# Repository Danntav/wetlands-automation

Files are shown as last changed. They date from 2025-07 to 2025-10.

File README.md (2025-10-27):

# Wetlands Automation System

An IoT-based automation system for monitoring and controlling wetland reactors in environmental research applications.

## Overview

This system implements a complete automation solution for wetland reactor monitoring using a distributed sensor network. The architecture consists of a master ESP32 unit with embedded HMI (LCD display and joystick) that coordinates data collection from up to 9 slave units via ESP-NOW wireless protocol. The master unit manages local control, real-time visualization, alarm monitoring, and fault-tolerant data logging to SD card.

## System Architecture

The system uses a master-slave architecture where the master ESP32 coordinates periodic data collection from distributed slave units. Communication is handled via ESP-NOW protocol for low-power wireless operation. The master unit features an interactive HMI for field operation, stores timestamped data with fault redundancy using an RTC module, and implements comprehensive alarm management for sensor anomalies and communication timeouts.

## Hardware Components

**Master Unit:**
- ESP32 microcontroller
- ST7735 LCD display (SPI interface)
- Analog joystick for menu navigation
- DS1307 RTC module (I2C)
- SD card module for data logging
- 3x RGB LED indicators for system status
- Custom PCB designed in KiCAD
- 3D-printed enclosure (SolidWorks)

**Slave Units:**
- ESP32 microcontroller
- Voltage and temperature sensors
- Wireless communication via ESP-NOW

## Software Implementation

The firmware is written in C/C++ using the Arduino framework. Key features include:

- **ESP-NOW Communication:** Implements request-response protocol with ACK for reliable data transfer between master and slaves
- **Real-time Clock:** DS1307 RTC provides accurate timestamps for all data points
- **Data Collection Cycle:** Configurable 30-minute intervals for automated sensor polling
- **Buffered Writing:** Collects data from all slaves before writing to SD card to minimize file operations
- **Alarm System:** Monitors voltage thresholds, temperature ranges, sensor failures, and communication timeouts
- **Interactive HMI:** Multi-screen menu system for viewing live data, historical logs, system status, and alarms
- **Fault Tolerance:** Redundant write verification and error recovery mechanisms

### Libraries Used

- **ESP-NOW & WiFi** version & version 1.2.7, Wireless communication stack
- **RTClib** version 2.1.4, DS1307 real-time clock interface
- **SD** version 1.3.0, SD card file system management
- **Adafruit_GFX & Adafruit_ST7735** version 1.12.1 & version 1.11.0, Display graphics and ST7735 driver
- **Wire** I2C communication for RTC

## Key Features

- Automatic data collection at configurable intervals (default: 30 minutes)
- Support for up to 9 distributed slave nodes
- Real-time monitoring with timestamped data
- Comprehensive alarm system with visual and logged notifications
- Field-accessible HMI with joystick navigation
- CSV data format for easy post-processing
- System health monitoring with LED status indicators
- Communication timeout detection and alerts

## Getting Started

### Hardware Setup

1. Assemble the master PCB with ESP32, display, RTC, SD module, and joystick
2. Install components in the 3D-printed enclosure
3. Program each slave unit with unique MAC address
4. Deploy slave units at monitoring locations
5. Power on the system and verify all slaves are detected

### Software Installation

```bash
git clone https://github.com/Danntav/wetlands-automation.git
cd wetlands-automation
```

Install required libraries in Arduino IDE, configure ESP32 board settings, and update slave MAC addresses in the master firmware before uploading.

## Project Structure

```
wetlands-automation/
├── firmware/
│   ├── master/
│   │   ├── master.ino
│   │   ├── MenuManager.h
│   │   ├── LedAnimations.h
│   │   └── DataStructures.h
│   └── slave/
├── hardware/
│   ├── pcb/              # KiCAD PCB files
│   └── enclosure/        # SolidWorks 3D models
└── docs/
```

## HMI Operation

The embedded Human-Machine Interface provides:
- **Main Menu:** System overview with active slave count and last update times
- **Board Data:** Individual slave readings with voltage and temperature
- **Alarms:** Real-time alerts for sensor anomalies and communication failures
- **Error Log:** Historical system errors with timestamps
- **System Info:** RTC status, SD card status, and overall health

Navigation is performed using the analog joystick (up/down/left/right/click).

## Data Logging

Data is logged in CSV format with the following structure:
```
Date,Time,BoardID,Voltage,Temperature
```

The system implements:
- Buffered writes to minimize SD card wear
- Automatic file creation with headers
- Timestamp verification via RTC
- Error logging for failed operations
- Visual feedback via LED indicators

## Alarm System

The system monitors and alerts for:
- Voltage readings outside safe range (configurable thresholds)
- Temperature anomalies beyond expected limits
- Sensor hardware failures (invalid readings)
- Communication timeouts (no response from slaves)

Alarms are displayed on the HMI, stored in memory, and indicated via blinking red LED.

## Configuration

System parameters can be adjusted in the firmware:
- `COLLECTION_INTERVAL_MS`: Data collection frequency (default: 30 minutes)
- `VOLTAGE_MIN/MAX`: Voltage alarm thresholds
- `TEMP_MIN/MAX`: Temperature alarm thresholds
- `COMM_TIMEOUT_MS`: Communication timeout duration
- `TOTAL_SLAVES`: Number of connected slave units

## Contributing

Contributions, issues, and feature requests are welcome. Feel free to check the issues page or submit pull requests.

## License

MIT License - see [LICENSE](LICENSE) file for details.

## Author

**Daniel Oliveira Tavares**

LinkedIn: [daniel-otavares](https://www.linkedin.com/in/daniel-otavares)

Email: danieloftavares@gmail.com

GitHub: [@Danntav](https://github.com/Danntav)

## Future Improvements

- [ ] Cloud connectivity for remote monitoring via MQTT or HTTP
- [ ] Mobile app integration for real-time alerts
- [ ] Additional sensor types (pH, dissolved oxygen, flow rate)
- [ ] Solar power system with battery management
- [ ] Web dashboard for data visualization and historical analysis
- [ ] Machine learning for predictive maintenance
- [ ] LoRa support for extended range communication

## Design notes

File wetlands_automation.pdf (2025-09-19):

### AUTOMAÇÃO WETLANDS por SISTEMA IoT

### Yara Carvalho Gomes

A automação visa em primeiro plano agilizar o processo de coleta de informações do sistema Wetlands. Foi proposto uma solução IoT com o uso de microcontroladores e sensores para monitorar continuamente os reatores. Estes dados serão armazenados localmente em um cartão de memória, do qual pode ser removido pelo operador e inserido em um computador para futuras análises das informações coletadas.
(Caso queira ver direto a parte prática → pular para página X)

Lógica do sistema
A organização geral do sistema consiste na lógica Mestre-Escravo. Os microcontroladores Escravos são responsáveis por coletar informações de tensão e temperatura de cada reator de Wetlands, e posteriormente enviar estes dados coletados ao microcontrolador Mestre, atuante como receptor central do conjunto. Os ESP32 Escravos são identificados com um código de 1 a 9. O Mestre é único, e é responsável por tratar o tráfego de informações recebidas de todos os Escravos, e armazená-las de forma sequencial em um cartão de memória local.
Uma vez que o local de implantação do circuito conta com acesso à rede elétrica, optou-se por não utilizar baterias para alimentar o sistema IoT, evitando assim gastos. Foram utilizadas 3 fontes chaveadas 12V (Volts) e 5A (Amperes) que convertem a tensão alternada da tomada de 110v para a tensão contínua de 12v. Foi adicionado um módulo Step-Down LM2596S na saída da fonte para regular a tensão e garantir alimentação para todo o sistema.
Foi determinada a coleta de dados a cada 5 minutos, resultando em 12 medições por hora, 288 medições por dia de cada reator. Dessa maneira, garante-se alta resolução e precisão das informações adquiridas dos reatores.

Escravos
O diagrama de conexão para todos os Escravos são semelhantes. Para cada reator haverá um sistema único, com o intuito de deixá-lo modular e facilitar a depuração.
O componente principal é o microcontrolador de baixo consumo ESP32-DevKitV1 desenvolvido pela empresa Espressif Systems. Dentre algumas de suas especificações, possui: processador Xtensa Dual-Core 32-bit LX6 com clock máximo de 240MHz; memória Flash programável de 4MB e memória RAM de 520 KBytes; possui 25 portas programáveis para entrada e/ou saída de dados (GPIO). conexão Bluetooth no padrão 4.2; conexão WiFi de 2.4GHz, podendo atuar como ponto de acesso, estação ou ponto de acesso+estação [1].
Para medição da temperatura, foi escolhido o sensor DS18B20 fabricado pela empresa Dallas Semiconductor, modelo resistente à água. Opera na faixa de -10°C até +85°C com precisão de ±0.5°C. A informação coletada pelo sensor é enviada ao microcontrolador por apenas um fio [2].
A medição de tensão do sistema é realizada através do módulo conversor analógico-digital, o ADS1115, fabricado pela empresa Texas Instruments. Este possui resolução de 16-bit, moderadamente maior se comparado com o conversor analógico-digital presente no próprio ESP32, que é de 12-bit. [3]
O sistema conta também com 3 LEDs (Light Emitting Diode ou Diodo Emissor de Luz) genéricos de 5mm, para dar um feedback visual do estado do sistema. Segue abaixo o diagrama feito no software Fritzing do sistema Escravo presente em cada um dos 9 reatores.

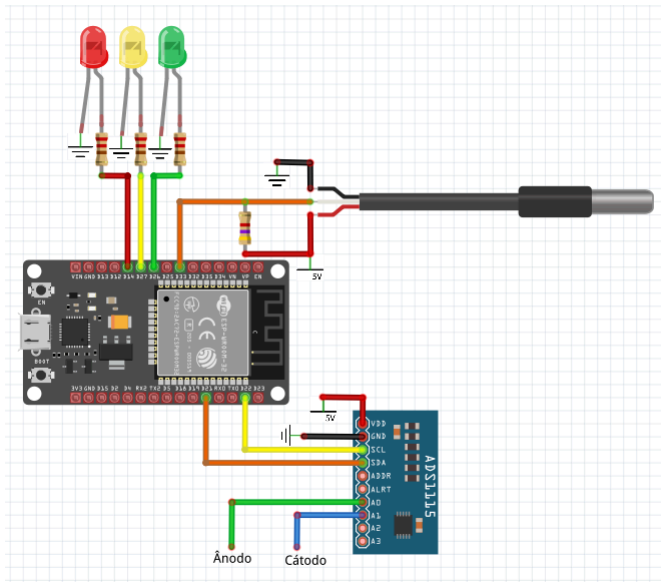
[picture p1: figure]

Mestre
O conjunto Mestre conta com módulos específicos e diferentes daqueles encontrados nos Escravos, com exceção do microcontrolador ESP32 e dos LEDs. O módulo DS1307 é um circuito integrado de relógio de tempo real (RTC, Real Time Clock) fabricado pela empresa Maxim Integrated, que conta com uma bateria e com um calendário interno. Ele marca segundos, minutos, horas, dia do mês, mês, dia da semana, ano, e faz a compensação automática para meses com menos de 31 dias e para anos bissextos. Na falta de energia, a contagem do tempo é garantida por meio de bateria. A comunicação com este módulo é feita via barramento I2C com o microcontrolador.[5]
Para salvar os dados advindos dos Escravos, foi utilizado um módulo de cartão de memória microSD genérico. Sua comunicação com o ESP principal é feita através do protocolo SPI (Serial Peripheral Interface)[6]. Os dados são gravados no cartão microSD utilizando o sistema de arquivos FAT32. Isso permite que o arquivo contento todas as informações seja lido diretamente em qualquer computador compatível.
Para facilitar a visualização de algumas informações em campo do sistema, como últimas medições dos reatores e alertas de erro, foi implementado um menu interativo composto por dois módulos. O primeiro, uma tela onde é possível visualizar as informações, o módulo genérico display LCD ST7735 TFT de 1.8 polegadas e que conta com resolução de 128x160 pixels. Sua comunicação com o Mestre é feita via SPI. O próximo, o controle para interagir com o menu, o módulo também genérico KY-023 joystick. Ele possui dois potenciômetros internos responsáveis por identificar a posição de movimento do analógico, além de um botão digital que é ativado quando o joystick é pressionado. Sua conexão com o microprocessador é feita via portas GPIO.
O sistema Mestre será colocado à parte em uma caixa específica e montado sobre uma placa de circuito impressa. O intuito é o operador interagir apenas com o módulo central Mestre, e não com os Escravos.
Segue abaixo o diagrama de conexões do ESP32 Mestre feito no software Fritzing.

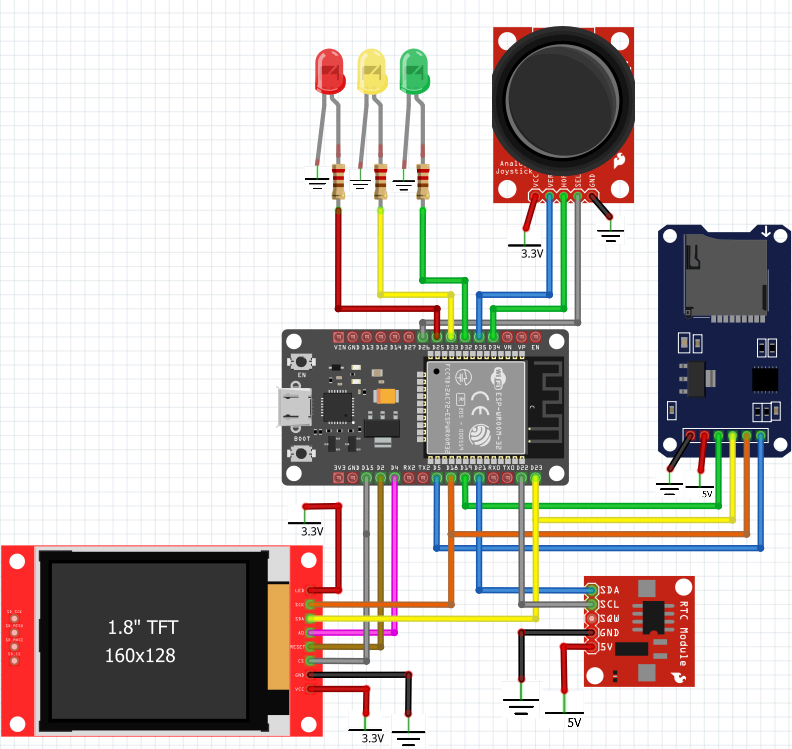
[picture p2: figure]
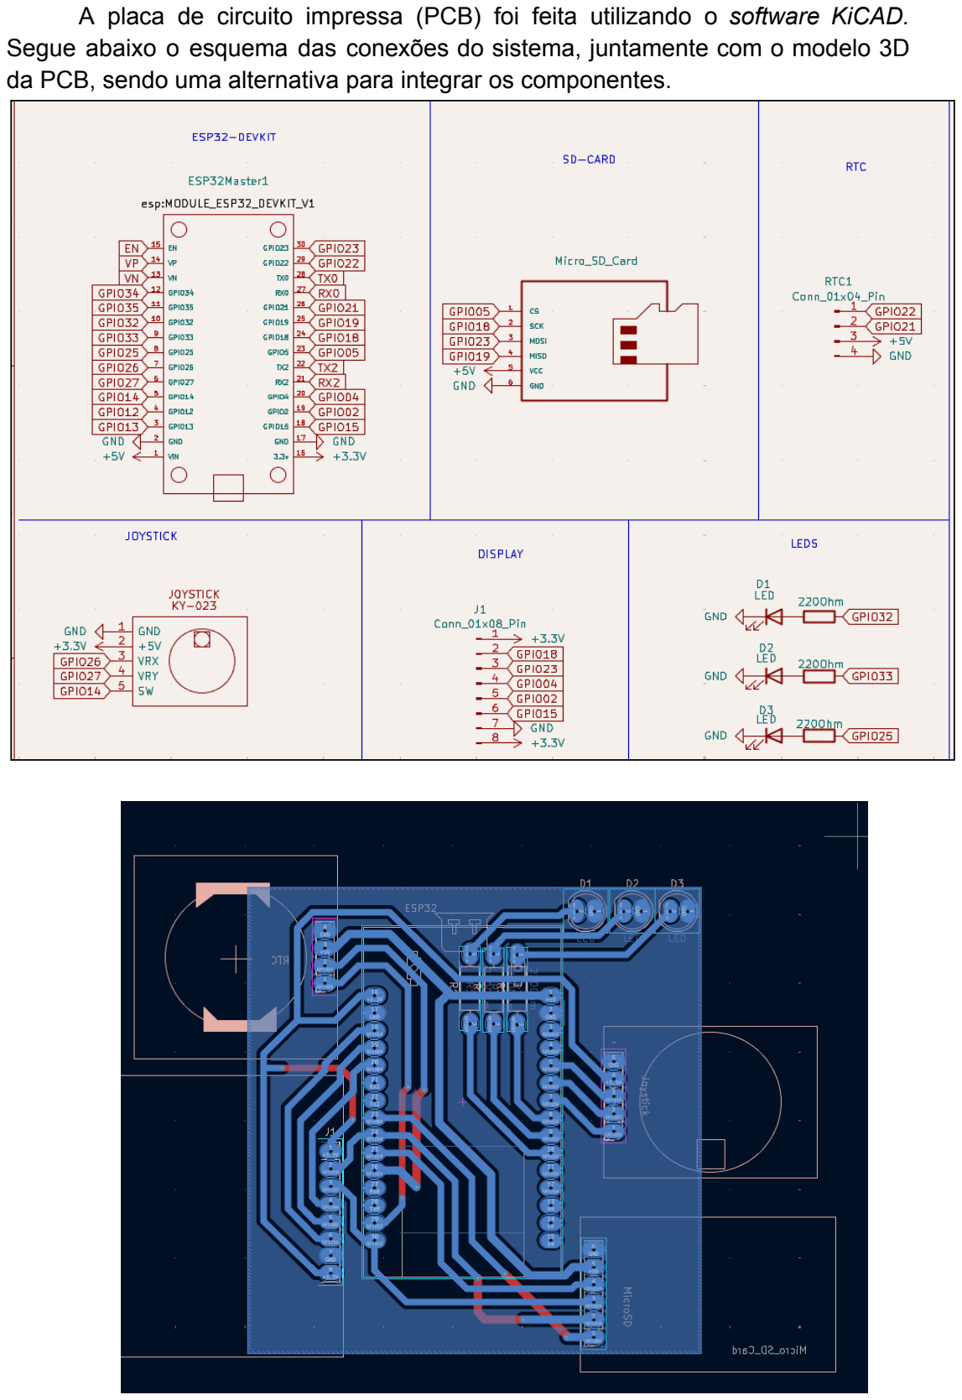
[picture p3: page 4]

A placa de circuito impressa (PCB) foi feita utilizando o software KiCAD. Segue abaixo o esquema das conexões do sistema, juntamente com o modelo 3D da PCB, sendo uma alternativa para integrar os componentes.

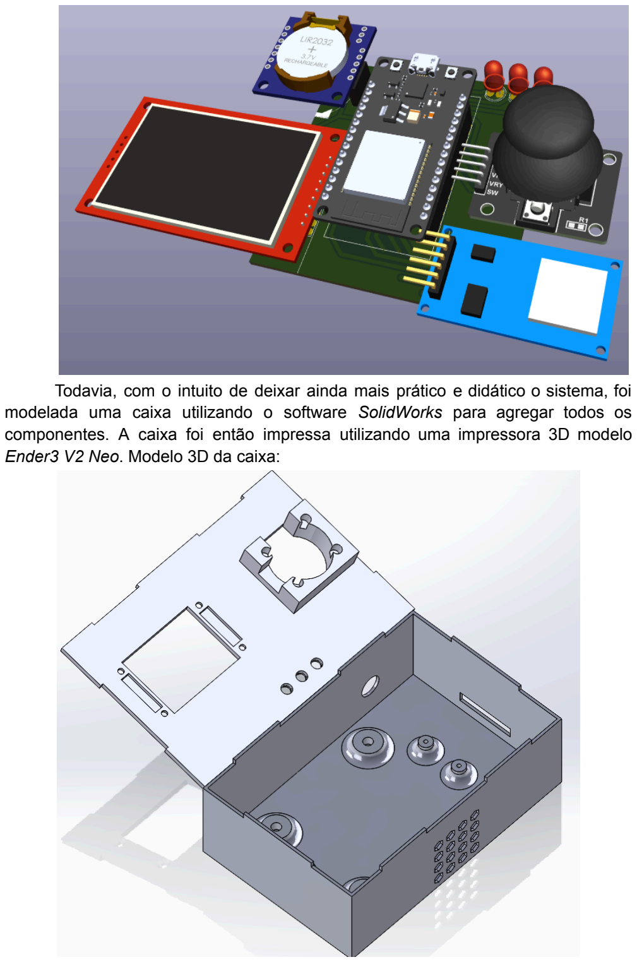
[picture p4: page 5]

Todavia, com o intuito de deixar ainda mais prático e didático o sistema, foi modelada uma caixa utilizando o software SolidWorks para agregar todos os componentes. A caixa foi então impressa utilizando uma impressora 3D modelo Ender3 V2 Neo. Modelo 3D da caixa:

Imagem do sistema real:

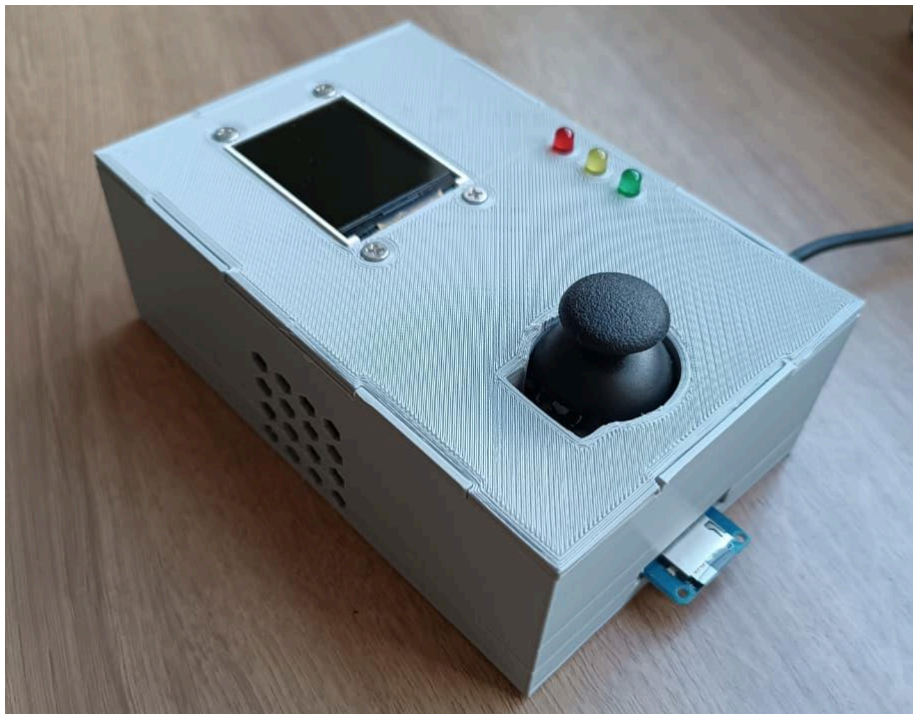
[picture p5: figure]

Passo a passo de como tudo funciona
Inicialmente, todo o sistema estará ligado e ativo. O ESP32 Mestre estará continuamente analisando o tempo do sistema baseado no módulo RTC. A cada 5 minutos (tempo estipulado anteriormente) o Mestre enviará um sinal de solicitação para o ESP32 Escravo número 1, para que este faça as medições no tanque em que está acoplado. Após o Escravo 1 coletar os dados por meio dos sensores, ele envia esta informação coletada juntamente com seu identificador (ID) para o Mestre. O Mestre armazena estes dados recebidos (adicionando também o horário de recebimento) de forma sequencial no cartão de memória.
Se o processo acontecer com sucesso no Escravo com ID 1, o Mestre envia uma mensagem de confirmação Acknowledgment (ACK) de volta ao ESP32 Escravo a fim de garantir conformidade entre os pares. Em seguida, todo o processo se repete para demais Escravos, continuamente durante todo o dia.
O cartão de memória ficará de fácil acesso em um caixa do qual o operador poderá removê-lo e transferir as informações para um computador, para futuras análises.

Lógica do sistema em forma de diagrama
Diagrama simplificado:

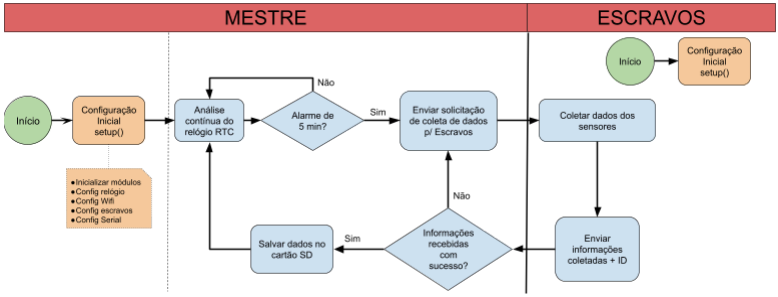
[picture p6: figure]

Troca de informação
A troca de informações entre os ESPs é feita via protocolo ESP-NOW. Este protocolo foi desenvolvido pela própria Espressif e é uma forma de comunicação sem fio que permite que múltiplos dispositivos se comuniquem entre si sem a necessidade de uma rede Wi-Fi.[7][8]

Mecanismos de Redundância
A fim de evitar perda de dados, alguns mecanismos de segurança foram implementados.
O primeiro mecanismo é referente à coleta de dados dos sensores. O sensor que mede a tensão e o que mede a temperatura, realiza 5 medições nos reatores e pegam a média desses valores como valor final de suas respectivas medições. Dessa maneira garante-se maior estabilidade da informação coletada e evita ruídos acentuados do sistema.
O segundo mecanismo é referente às trocas de mensagem. Para garantir que a mensagem do ESP32 Escravo chegue ao ESP32 Mestre, o Mestre envia de volta ao Escravo uma confirmação Acknowledgment (ACK). Caso o Escravo não receba esta confirmação em um intervalo de tempo de 2 segundos, é possível que a informação tenha se perdido ou se corrompido no caminho, e com isso ele a envia novamente, em um total de até 3 vezes.
Ainda no contexto de troca de mensagens, o próximo mecanismo de segurança se encontra no Mestre. Caso a informação recebida de um dos Escravos esteja fora da faixa de valores (Temperatura: < 0°C ou > 50°C; Voltagem <= 0.00V) ou ainda que temperatura = -127°C e de tensão = 0.00V, uma mensagem de erro irá piscar no display. Estes valores indicam que algo não está de acordo nas medições, e o display indicará em qual reator se encontra o conflito.
Já com o intuito de evitar possíveis perdas de dados na ausência do cartão de memória durante a transferência de informação, o cronômetro de 5 minutos do Mestre é pausado ao remover o cartão SD. Além disso, um LED vermelho irá prover informação visual do momento de transferência de dados, indicando que é aconselhável evitar manusear o cartão SD naquele instante. Um LED verde indica que é possível removê-lo sem perigo de perdas. Além disso, após salvar as informações no cartão de memória, o Mestre faz a leitura do último registro gravado para confirmar que a escrita foi realizada corretamente.

Armazenagem e análise de informações coletadas
As informações serão salvas no cartão SD de forma sequencial em um mesmo arquivo. Caso seja o primeiro registro e o arquivo não exista, o Mestre cria este arquivo.

As informações serão salvas seguindo o padrão: DATA,ID,TEMPERATURA,TENSÃO.

Formato da DATA:
HH:mm:SS:DD:MM:AAAA ( hora - minuto - segundo - dia - mês - ano).

Um exemplo de possível registro no cartão SD: 16:15:39:12:10:2025,5,25.71,0.342
“16 horas, 15 minutos, 39 segundos, dia 12, mês 10, ano 2025, ID=5, temp=25.71°C, voltagem=0.342V”

O formato do arquivo gerado é do tipo Comma Separated Value (.csv). É um arquivo de texto simples que armazena dados tabulares separados com vírgula, e é compatível com inúmeros programas, inclusive o Microsoft Excel e Google Sheets. Assim, os dados podem ser facilmente analisados da forma que convier ao pesquisador.

Fontes:
[1] https://www.robocore.net/wifi/esp32-wifi-bluetooth[2]https://www.alldatasheet.com/datasheet-pdf/view/58557/DALLAS/DS18B20.html[3]https://www.ti.com/lit/ds/symlink/ads1115.pdf?ts=1741234332539[4]https://www.espressif.com/sites/default/files/documentation/esp32_datasheet_en.pdf[5]https://www.alldatasheet.com/html-pdf/58481/DALLAS/DS1307/180/1/DS1307.html [6]Desenvolvimento de solução IoT para monitoramento de gases [7]https://docs.espressif.com/projects/esp-idf/en/stable/esp32/api-reference/network/esp_no w.html (https://docs.espressif.com/projects/esp-idf/en/stable/esp32/api-reference/network/esp_now.html)
[8]https://randomnerdtutorials.com/esp-now-esp32-arduino-ide/

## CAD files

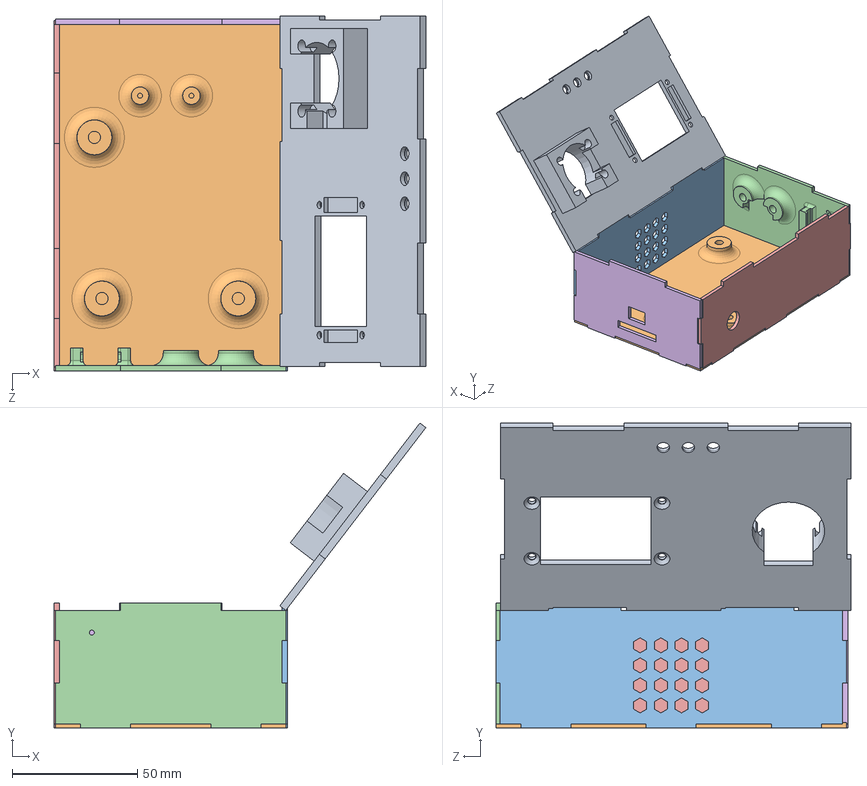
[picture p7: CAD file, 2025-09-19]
SolidWorks/Box_Pieces.SLDASM
148.5 x 121.8 x 141.8 mm
R_Side
F_side
L_Side
B_Side
Bottom
Top

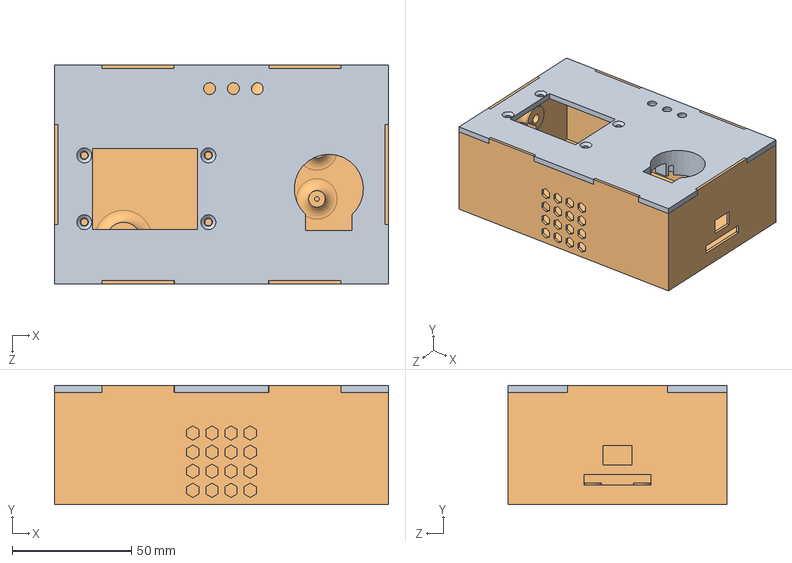
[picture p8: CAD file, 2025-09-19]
SolidWorks/Assem3.SLDASM
140.0 x 50.0 x 92.0 mm
Base
Top

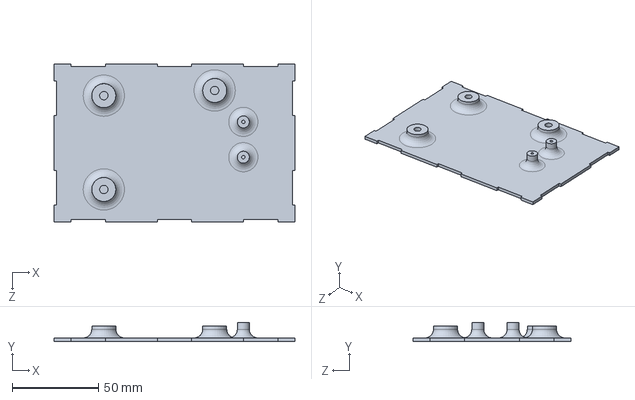
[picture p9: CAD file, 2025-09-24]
SolidWorks/Bottom.SLDPRT
140.0 x 11.1 x 92.0 mm

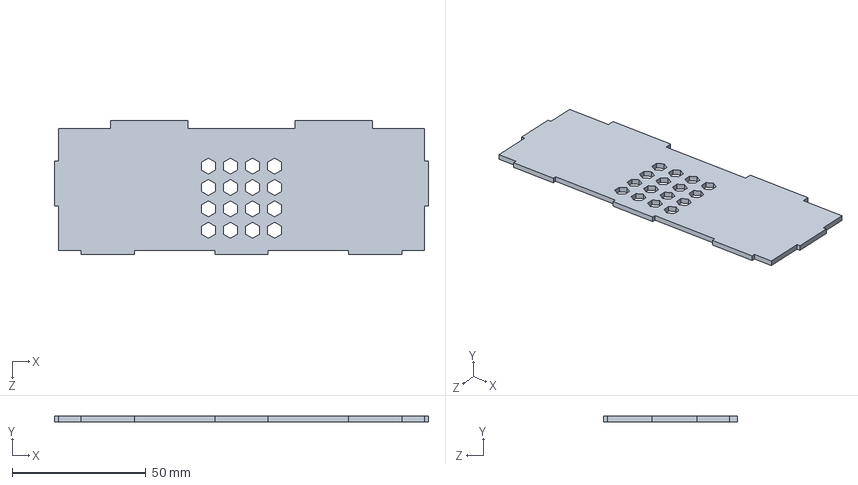
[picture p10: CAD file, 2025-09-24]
SolidWorks/B_Side.SLDPRT
140.0 x 2.10 x 50.0 mm

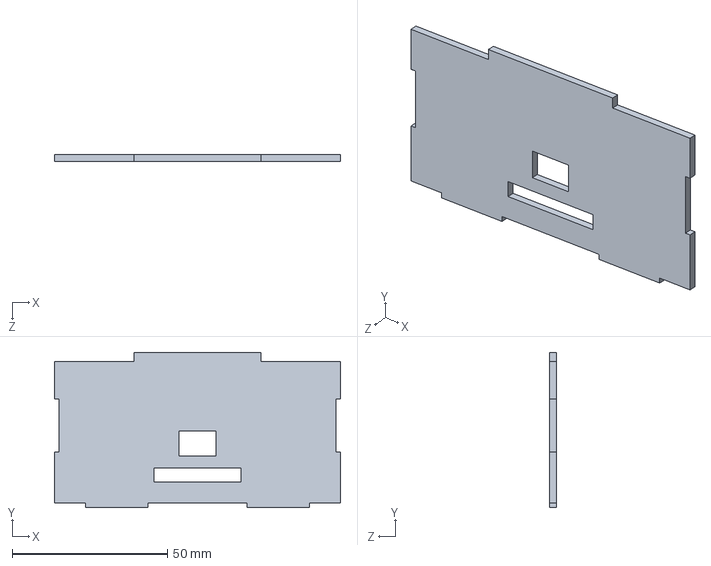
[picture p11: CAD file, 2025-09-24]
SolidWorks/R_Side.SLDPRT
92.0 x 50.0 x 2.10 mm

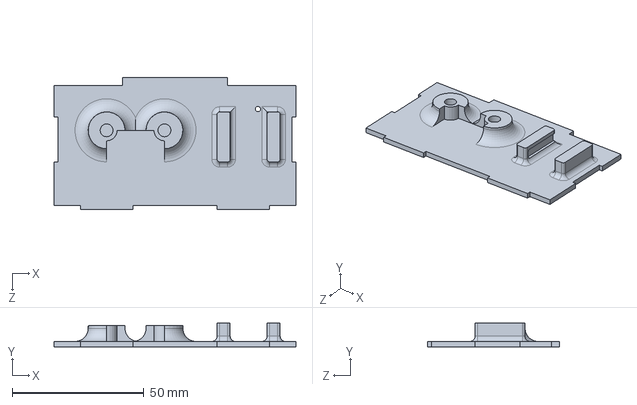
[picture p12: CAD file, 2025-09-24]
SolidWorks/L_Side.SLDPRT
92.0 x 9.10 x 50.0 mm

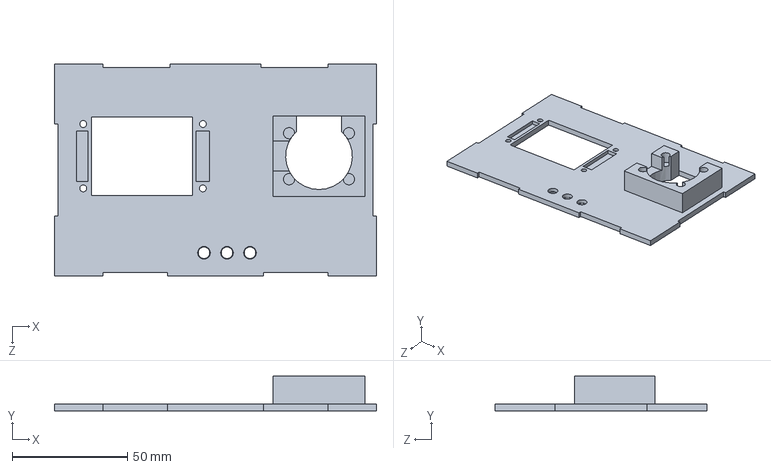
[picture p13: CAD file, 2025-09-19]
SolidWorks/Top.SLDPRT
140.0 x 15.0 x 92.0 mm

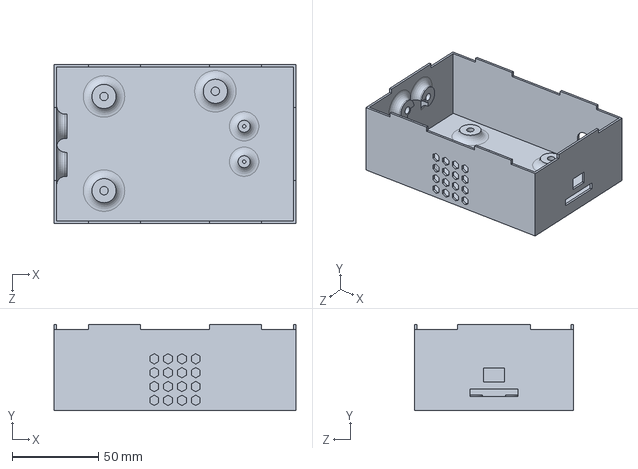
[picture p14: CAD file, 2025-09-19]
SolidWorks/Base.SLDPRT
140.0 x 50.0 x 92.0 mm

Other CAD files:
SolidWorks/F_side.SLDPRT
SolidWorks/Base - Backup.SLDPRT
SolidWorks/B_Side.STL
SolidWorks/Bottom.STL
SolidWorks/F_side.STL
SolidWorks/L_Side.STL
SolidWorks/R_Side.STL

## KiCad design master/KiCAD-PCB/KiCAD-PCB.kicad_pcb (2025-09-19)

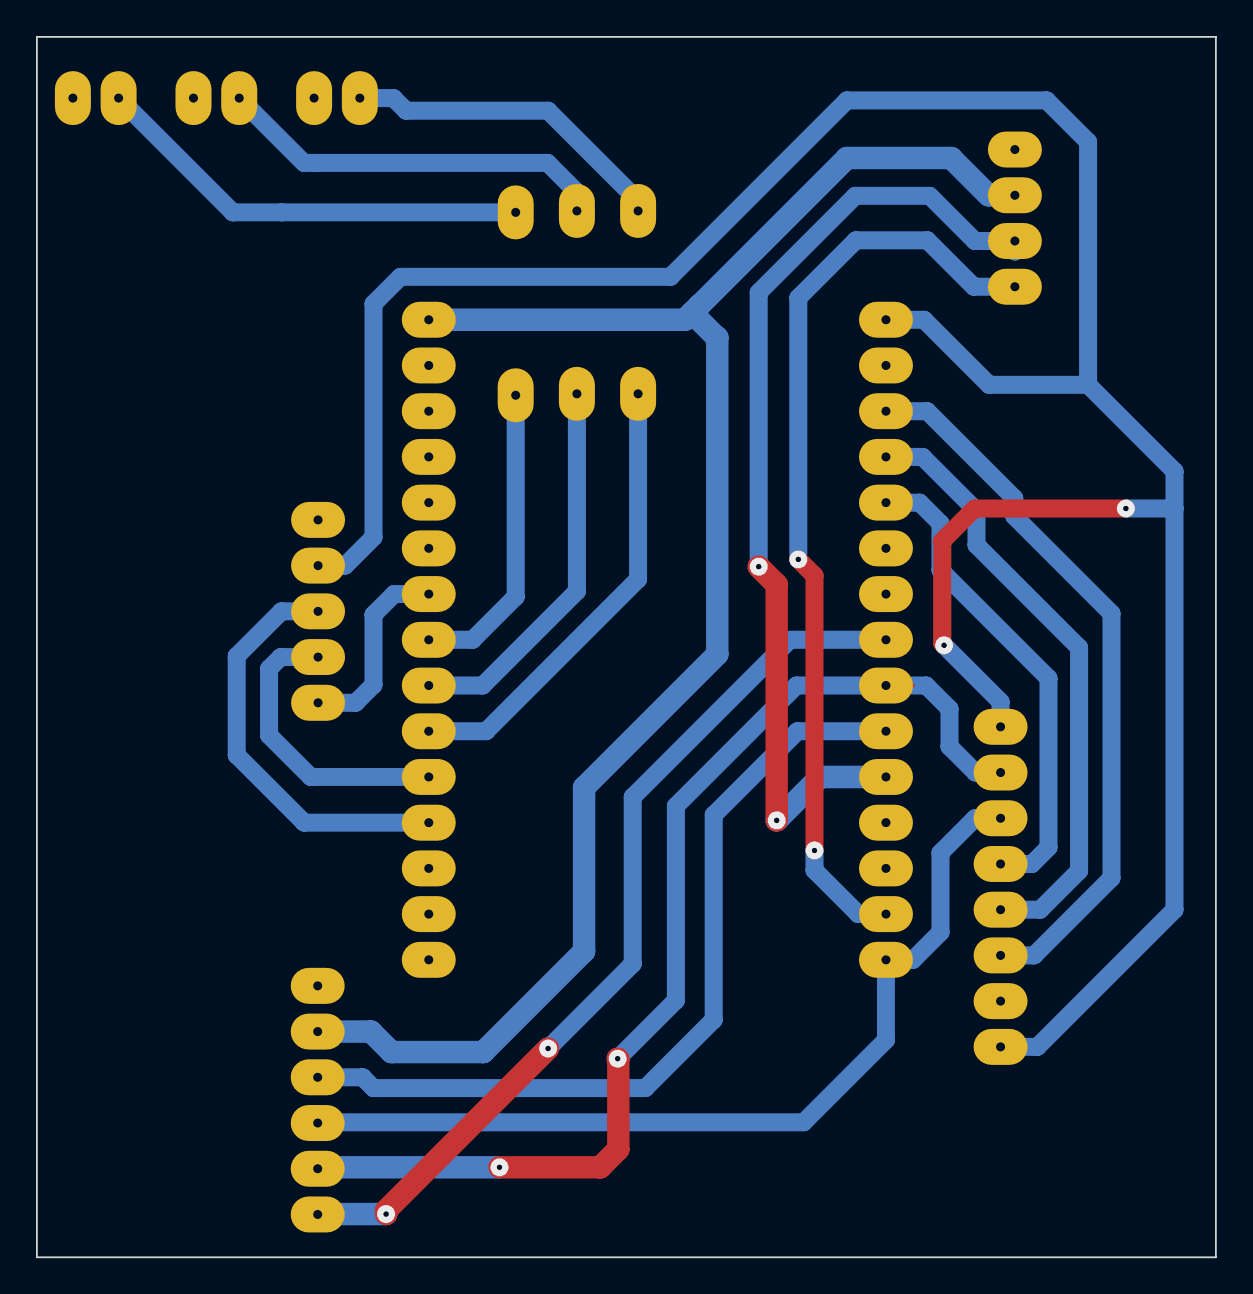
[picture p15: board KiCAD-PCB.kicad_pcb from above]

Board: 2 copper layers, 65.5 x 67.8 mm, 11 parts (1 on the bottom side), 21 nets.

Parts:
ESP32: MODULE_ESP32_DEVKIT_V1
J1: Conn_01x08_Pin; PinSocket_1x08_P2.54mm_Vertical
Joystick1: PinSocket_1x05_P2.54mm_Vertical
LED1: LED1; LED_D5.0mm
LED2: LED2; LED_D5.0mm
LED3: LED3; LED_D5.0mm
MicroSD: Micro_SD_Card; PinSocket_1x06_P2.54mm_Vertical
R1, R2, R3: 220Ohm; R_Axial_DIN0207_L6.3mm_D2.5mm_P10.16mm_Horizontal
RTC: Conn_01x04_Pin; PinSocket_1x04_P2.54mm_Vertical

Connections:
+3.3V: ESP32.16 (3.3v), J1.1, J1.8, Joystick1.4 (VRY)
+5V: ESP32.1 (VIN), MicroSD.5 (VCC), RTC.3
GND: ESP32.2 (GND), ESP32.17 (GND), J1.7, Joystick1.5 (SW), LED1.1 (K), LED2.1 (K), LED3.1 (K), MicroSD.6 (GND), RTC.4
GPIO02: ESP32.19 (GPIO2), J1.5
GPIO04: ESP32.20 (GPIO4), J1.4
GPIO05: ESP32.23 (GPIO5), MicroSD.1 (CS)
GPIO15: ESP32.18 (GPIO15), J1.6
GPIO18: ESP32.24 (GPIO18), J1.2, MicroSD.2 (SCK)
GPIO19: ESP32.25 (GPIO19), MicroSD.4 (MISO)
GPIO21: ESP32.26 (GPIO21), RTC.2
GPIO22: ESP32.29 (GPIO22), RTC.1
GPIO23: ESP32.30 (GPIO23), J1.3, MicroSD.3 (MOSI)
GPIO25: ESP32.8 (GPIO25), R3.2
GPIO26: ESP32.7 (GPIO26), Joystick1.1 (GND)
GPIO32: ESP32.10 (GPIO32), R1.2
GPIO33: ESP32.9 (GPIO33), R2.2
GPIO34: ESP32.12 (GPIO34), Joystick1.3 (VRX)
GPIO35: ESP32.11 (GPIO35), Joystick1.2 (+5V)
unnamed: LED1.2 (A), R1.1
unnamed: LED2.2 (A), R2.1
unnamed: LED3.2 (A), R3.1

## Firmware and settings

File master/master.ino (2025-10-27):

#include <esp_now.h>
#include <WiFi.h>
#include <RTClib.h>
#include <SD.h>
#include <Adafruit_GFX.h>
#include <Adafruit_ST7735.h>
#include <Wire.h>
#include "LedAnimations.h"
#include "MenuManager.h"
#include "DataStructures.h"

#define COLLECTION_INTERVAL_MS (30UL * 60UL * 1000UL)
#define NODE_ID_UNKNOWN 0

String boardLastUpdate[TOTAL_SLAVES];
unsigned long boardLastUpdateMillis[TOTAL_SLAVES];

// Buffer para armazenar os dados recebidos antes de gravar no SD
struct_message dataBuffer[TOTAL_SLAVES];
int bufferCount = 0;
// Flag para controlar o ciclo de gravação
bool isCollectionCycleActive = false;
unsigned long requestCycleStartTime = 0;

String alarmMsgs[MAX_ALARMS];
int alarmCount = 0;
bool hasActiveAlarms = false;
int alarmMenuOption = 0;

// Map all slave's MAC
const uint8_t slaveMacs[TOTAL_SLAVES][6] = {
  { 0x00, 0x4B, 0x12, 0x21, 0x32, 0xA8 },  // Slave 1
  { 0xE0, 0xE2, 0xE6, 0x63, 0x15, 0xA0 },  // Slave 2
  { 0x00, 0x4B, 0x12, 0x22, 0x43, 0xC0 },  // Slave 3
  { 0x38, 0x18, 0x2B, 0xE8, 0x6C, 0x2C },  // Slave 4
  { 0x14, 0x33, 0x5C, 0x02, 0xE8, 0x80 },  // Slave 5
  { 0x00, 0x4B, 0x12, 0x21, 0xE6, 0x68 },  // Slave 6
  { 0x20, 0x43, 0xA8, 0xE6, 0x0B, 0x30 },  // Slave 7
  { 0x14, 0x33, 0x5C, 0x02, 0xED, 0x6C },  // Slave 8
  { 0x6C, 0xC8, 0x40, 0x33, 0x76, 0x50 },  // Slave 9
};

// Master's MAC
//uint8_t masterMacAddress[] = {0x3C, 0x8A, 0x1F, 0x5E, 0x16, 0x48};

JoystickState readJoystick() {
  const int deadZone = 600;  // ignoring center noise
  const int center = 2048;
  static int prevX = center, prevY = center;  // store prev moving average readings
  const float alpha = 0.7;                    // valor médio do ADC para 3.3V

  int rawX = analogRead(JOY_X_PIN);
  int rawY = analogRead(JOY_Y_PIN);
  bool btn = digitalRead(JOY_BTN_PIN) == LOW;

  // Exponential moving average
  int x = alpha * rawX + (1 - alpha) * prevX;
  int y = alpha * rawY + (1 - alpha) * prevY;
  prevX = x;
  prevY = y;

  JoystickState js;

  if (x < center - deadZone) js.left = true;
  if (x > center + deadZone) js.right = true;
  if (y < center - deadZone) js.up = true;
  if (y > center + deadZone) js.down = true;
  js.click = btn;

  return js;
}

JoystickState prevJs;                    // last reading
unsigned long lastNavTime = 0;           // timestamp of the last move
const unsigned long NAV_DEBOUNCE = 200;  // 200 ms between changes
unsigned long lastJoyMove = 0;
// -------------------------------------

String errorMsgs[MAX_ERRORS];
int errorCount = 0;

MenuState currentState = MENU_MAIN;
int selectedOption = 0;
int currentBoardIndex = 0;
struct_message boards[TOTAL_SLAVES];

RTC_DS1307 rtc;  //DS1307

Adafruit_ST7735 tft = Adafruit_ST7735(TFT_CS, TFT_DC, TFT_RST); // Init ST7735 display

bool sdInitialized = false;


void setup() {
  pinMode(2, OUTPUT);
  digitalWrite(2, LOW);
  Serial.begin(115200);
  delay(1500);
  ledTurnOff();
  setupLeds();
  setupDisplay();
  delay(1500);

  setupRTC();
  delay(1000);

  setupSD();

  for (int i = 0; i < TOTAL_SLAVES; i++) {
    boards[i].id = NODE_ID_UNKNOWN;
    boards[i].voltage = 0.0;
    boards[i].temperature = 0.0;
    boardLastUpdate[i] = "Never";
    boardLastUpdateMillis[i] = 0;
  }

  for (int i = 0; i < MAX_ALARMS; i++) {
    alarmMsgs[i] = "";
  }
  alarmCount = 0;
  hasActiveAlarms = false;
  alarmMenuOption = 0;

  setupESPNow();
  delay(1000);
  setupJoy();
}


void loop() {
  handleJoystick();
  ledUpdateNewData();
  ledUpdateBlinking();
  updateAlarmLed();
  animateTitle();
  checkCommunicationAlarms();

  // Lógica principal de tempo para SOLICITAR dados
  if (!isCollectionCycleActive && (millis() - requestCycleStartTime >= COLLECTION_INTERVAL_MS)) {
    requestDataFromSlaves();
    requestCycleStartTime = millis(); // Marca o início do ciclo de coleta
    isCollectionCycleActive = true;
    Serial.println("Ciclo de coleta iniciado. Aguardando respostas...");
  }

  // Lógica para GRAVAR os dados após um tempo de espera
  if (isCollectionCycleActive && (millis() - requestCycleStartTime > 20000)) {
    writeBufferToSD();
    bufferCount = 0;
    isCollectionCycleActive = false; // Prepara para o próximo ciclo
  }
}


void setupESPNow() {
  // Set device as a Wi-Fi Station
  WiFi.mode(WIFI_STA);

  // Init ESP-NOW
  if (esp_now_init() != ESP_OK) {
    Serial.println("ERROR init ESP-NOW");
    logErrorDisplay("ERROR init ESP-NOW");
    ledAnimationBlinking(LED::red, 20);
    return;
  }
  esp_now_register_recv_cb(onDataRecv);
  // Register all Slaves
  for (int i = 0; i < TOTAL_SLAVES; i++) {
    esp_now_peer_info_t peerInfo = {};
    memcpy(peerInfo.peer_addr, slaveMacs[i], 6);
    peerInfo.channel = 0;
    peerInfo.encrypt = false;
    if (esp_now_add_peer(&peerInfo) != ESP_OK) {
      Serial.printf("Failed to add peer %d\n", i + 1);
      logErrorDisplay("Failed to add peer");
      ledAnimationBlinking(LED::red, 20);
    }
  }
  delay(1000);
  Serial.println("ESP-NOW Successfully initialized");
  ledAnimationBlinking(LED::green, 5);
}


void setupRTC() {
  Wire.begin(RTC_SDA, RTC_SCL);
  scanI2C();
  if (!rtc.begin()) {
    Serial.println("ERROR RTC not found!");
    logErrorDisplay("ERROR RTC not found!");
    ledAnimationBlinking(LED::red, 20);
  } else if (!rtc.isrunning()) {
    Serial.println("ERROR RTC not running");
    logErrorDisplay("ERROR RTC not running");
    ledAnimationBlinking(LED::red, 20);
    rtc.adjust(DateTime(2025, 7, 19, 16, 30, 0));
  } else {
    Serial.println("RTC successfully initialized");
    ledAnimationBlinking(LED::green, 5);
  }
}


void setupDisplay() {
  pinMode(TFT_CS, OUTPUT);
  pinMode(TFT_DC, OUTPUT);
  pinMode(TFT_RST, OUTPUT);
  pinMode(SD_CS, OUTPUT);
  digitalWrite(TFT_CS, HIGH);
  digitalWrite(SD_CS, HIGH);
  delay(50);
  digitalWrite(TFT_CS, LOW);
  SPI.begin(SD_SCK, SD_MISO, SD_MOSI, TFT_CS);
  Serial.println("Initializing display...");
  tft.initR(INITR_BLACKTAB);
  tft.setRotation(1);
  tft.fillScreen(ST77XX_BLACK);
  Serial.println("Display initialized successfully");
  digitalWrite(TFT_CS, HIGH);
  SPI.end();
  Serial.println("Starting initMenu...");
  initMenu(&tft);
  Serial.println("setupDisplay completed");
}


void setupJoy() {
  pinMode(JOY_X_PIN, INPUT);
  pinMode(JOY_Y_PIN, INPUT);
  pinMode(JOY_BTN_PIN, INPUT_PULLUP);
}


void setupSD() {
  Serial.println("Initializing SD card...");
  
  // Garante que outros dispositivos SPI estão desativados
  digitalWrite(TFT_CS, HIGH);
  digitalWrite(SD_CS, HIGH);
  delay(50);
  
  // Inicia SPI com os pinos corretos para o SD
  SPI.begin(SD_SCK, SD_MISO, SD_MOSI, SD_CS);
  delay(50);
  
  Serial.print("Testing SD card on CS pin: ");
  Serial.println(SD_CS);

  if (!SD.begin(SD_CS)) {
    Serial.println("SD Card initialization FAILED!");
    logErrorDisplay("SD Card failed!");
    sdInitialized = false;
    
    // Tenta listar arquivos para diagnóstico
    Serial.println("Attempting to list files on SD card...");
    File root = SD.open("/");
    if (root) {
      root.rewindDirectory();
      Serial.println("SD card content:");
      while (true) {
        File entry = root.openNextFile();
        if (!entry) break;
        Serial.print("  ");
        Serial.println(entry.name());
        entry.close();
      }
      root.close();
    }
  } else {
    Serial.println("SD Card initialized successfully.");
    sdInitialized = true;
    
    // Verifica se o arquivo existe, se não, cria cabeçalho
    if (!SD.exists(SD_FILE)) {
      File sdFile = SD.open(SD_FILE, FILE_WRITE);
      if (sdFile) {
        sdFile.println("Date,Time,BoardID,Voltage,Temperature");
        sdFile.close();
        Serial.println("Created new data file with header");
      }
    }
    Serial.println("SD card is ready for writing.");
  }
  SPI.end();
}


void requestDataFromSlaves() {
  Serial.println("\n=============================================");
  Serial.printf("[%s] - Iniciando novo ciclo de coleta de dados.\n", getTimestamp().c_str());
  Serial.println("=============================================");
  
  for (int i = 0; i < TOTAL_SLAVES; i++) {
    struct_request req;
    req.command = 1; // Comando para "coletar e enviar dados"

    const uint8_t* slaveMac = slaveMacs[i];
    esp_err_t result = esp_now_send(slaveMac, (uint8_t *) &req, sizeof(req));

    if (result == ESP_OK) {
      Serial.printf("Solicitacao enviada para o Escravo \[%d\]\n", i + 1);
      ledNewData();
    } else {
      char errorMsg[40];
      snprintf(errorMsg, sizeof(errorMsg), "Erro ao solicitar dados do Escravo %d", i + 1);
      Serial.println(errorMsg);
      logErrorDisplay(errorMsg);
    }
    delay(300); // Um pequeno intervalo entre as solicitações para não sobrecarregar
  }
}


void onDataRecv(const esp_now_recv_info *info, const uint8_t *data, int len) {
  Serial.println("PACOTE RECEBIDO --> Processando mensagem...");
  ledNewData();
  // Validações rápidas
  if (len != sizeof(struct_message)) return;
  struct_message msg;
  memcpy(&msg, data, sizeof(msg));
  if (msg.id <= 0 || msg.id > TOTAL_SLAVES) return;

  // Filtro para evitar processamento duplicado
  int idx = msg.id - 1;
  if (idx < 0 || idx >= TOTAL_SLAVES) return;
  static unsigned long lastProcessTime[TOTAL_SLAVES] = {0};
  if (millis() - lastProcessTime[idx] < 1000) { // Ignora se já processou há menos de 1s
    Serial.printf("Ignorando mensagem duplicada do Slave %d\n", msg.id);
    return;
  }
  lastProcessTime[idx] = millis();
  
  // Envia o ACK imediatamente
  ack_message ack = { .id = msg.id, .ok = true };
  esp_now_send(info->src_addr, (uint8_t *)&ack, sizeof(ack));
  Serial.println("Enviando ACK...");
    
  // Atualiza dados (SEM duplicata por agora)
  boards[idx] = msg;
  boardLastUpdate[idx] = getTimestamp();
  boardLastUpdateMillis[idx] = millis();
  
  // Verifica alarmes
  checkForAlarms(msg, idx);

  // Adiciona a mensagem ao buffer se houver espaço
  if (bufferCount < TOTAL_SLAVES) {
    dataBuffer[bufferCount] = msg;
    bufferCount++;
    ledNewData(); // Pisca o LED para feedback visual
  }
  // Esta parte é ótima para depuração e não atrapalha, pois o ACK já foi enviado.
  Serial.printf("\n=== PACOTE RECEBIDO (Slave %d) ===\n", msg.id);
  Serial.printf("  Voltagem: %.4fV\n", msg.voltage);
  Serial.printf("  Temperatura: %.2f°C\n", msg.temperature);
  Serial.println("  -> ACK enviado, dados atualizados e adicionados ao buffer de gravacaoo.");
  Serial.println("==================================");
}


String getTimestamp() {
  if (!rtc.isrunning()) {
    Serial.println("ERROR RTC not running");
    logErrorDisplay("ERROR RTC not running");
    return "1970-01-01 00:00:00";
  }
  DateTime now = rtc.now();
  char buf[20];
  snprintf(buf, sizeof(buf), "%02d-%02d-%04d %02d:%02d:%02d",
           now.day(), now.month(), now.year(),
           now.hour(), now.minute(), now.second());
  return String(buf);
}


void scanI2C() {
  Serial.println("Scanning I2C bus...");
  for (byte addr = 1; addr < 127; addr++) {
    Wire.beginTransmission(addr);
    if (Wire.endTransmission() == 0) {
      Serial.printf("Device found at address 0x%02X\n", addr);
    }
  }
}


void logErrorDisplay(String msg) {
  digitalWrite(SD_CS, HIGH);
  digitalWrite(TFT_CS, HIGH);
  SPI.begin(SD_SCK, SD_MISO, SD_MOSI, TFT_CS);
  delay(10);
  digitalWrite(TFT_CS, LOW);
  String timestamp = getTimestamp();
  String fullErrorMsg = timestamp + "@" + msg;
  if (errorCount < MAX_ERRORS) {
    errorMsgs[errorCount++] = fullErrorMsg;
  } else {
    for (int i = 1; i < MAX_ERRORS; i++) {
      errorMsgs[i - 1] = errorMsgs[i];
    }
    errorMsgs[MAX_ERRORS - 1] = fullErrorMsg;
  }
  digitalWrite(TFT_CS, HIGH);
  SPI.end();
}


void handleJoystick() {
  JoystickState js = readJoystick();
  unsigned long now = millis();
  if (now - lastNavTime > NAV_DEBOUNCE) {
    if (js.left && !prevJs.left) {
      updateMenu(true, false, false, false, false);
      lastNavTime = now;
    } else if (js.right && !prevJs.right) {
      updateMenu(false, true, false, false, false);
      lastNavTime = now;
    } else if (js.up && !prevJs.up) {
      updateMenu(false, false, true, false, false);
      lastNavTime = now;
    } else if (js.down && !prevJs.down) {
      updateMenu(false, false, false, true, false);
      lastNavTime = now;
    } else if (js.click && !prevJs.click) {
      updateMenu(false, false, false, false, true);
      lastNavTime = now;
    }
  }
  prevJs = js;
}


void addAlarm(String message) {
  String timestamp = getTimestamp();
  String fullAlarmMsg = timestamp + " " + message;
  
  if (alarmCount < MAX_ALARMS) {
    alarmMsgs[alarmCount++] = fullAlarmMsg;
  } else {
    // Remove o mais antigo e adiciona o novo
    for (int i = 1; i < MAX_ALARMS; i++) {
      alarmMsgs[i - 1] = alarmMsgs[i];
    }
    alarmMsgs[MAX_ALARMS - 1] = fullAlarmMsg;
  }
  hasActiveAlarms = true;
  Serial.println("ALARME: " + message);
}


void clearAlarms() {
  for (int i = 0; i < alarmCount; i++) {
    alarmMsgs[i] = "";
  }
  alarmCount = 0;
  hasActiveAlarms = false;
  Serial.println("Alarmes limpos");
}

// Função para verificar alarmes nos dados recebidos
void checkForAlarms(const struct_message &msg, int boardIndex) {
  char alarmMsg[80];
  
  // Verifica voltagem
  if (msg.voltage <= VOLTAGE_MIN || msg.voltage > VOLTAGE_MAX) {
    snprintf(alarmMsg, sizeof(alarmMsg), "Board %d: Voltagem anormal %.2fV", msg.id, msg.voltage);
    addAlarm(String(alarmMsg));
  }
  
  // Verifica temperatura
  if (msg.temperature <= TEMP_MIN || msg.temperature > TEMP_MAX) {
    snprintf(alarmMsg, sizeof(alarmMsg), "Board %d: Temperatura anormal %.1f°C", msg.id, msg.temperature);
    addAlarm(String(alarmMsg));
  }
  
  // Verifica valores inválidos típicos de sensores com problema
  if (msg.voltage <= 0.0 || msg.temperature <= -100) {
    snprintf(alarmMsg, sizeof(alarmMsg), "Board %d: Sensor com falha (V=%.2f T=%.1f)", msg.id, msg.voltage, msg.temperature);
    addAlarm(String(alarmMsg));
  }
}

// Verifica timeouts de comunicação
void checkCommunicationAlarms() {
  static unsigned long lastCommCheck = 0;
  if (millis() - lastCommCheck < 60000) return; // Verifica apenas a cada minuto
  lastCommCheck = millis();
  
  for (int i = 0; i < TOTAL_SLAVES; i++) {
    if (boardLastUpdateMillis[i] > 0) {  // Só verifica se já recebeu dados antes
      unsigned long timeSinceUpdate = millis() - boardLastUpdateMillis[i];
      if (timeSinceUpdate > COMM_TIMEOUT_MS) {
        char alarmMsg[60];
        snprintf(alarmMsg, sizeof(alarmMsg), "Board %d: Sem comunicacao %lu min", 
                i + 1, timeSinceUpdate / 60000);
        addAlarm(String(alarmMsg));
      }
    }
  }
}


String getSlaveStatus(int slaveId) {
  int idx = slaveId - 1;
  if (idx < 0 || idx >= TOTAL_SLAVES) return "";
  
  String status = "";
  struct_message board = boards[idx];
  
  // Timeout de comunicação
  if (boardLastUpdateMillis[idx] > 0) {
    unsigned long timeSinceUpdate = millis() - boardLastUpdateMillis[idx];
    if (timeSinceUpdate > COMM_TIMEOUT_MS) {
      status += "X"; // Timeout
    }
  }
  
  // Valores fora do range
  if (board.voltage <= VOLTAGE_MIN || board.voltage > VOLTAGE_MAX) {
    status += "V"; // Voltage problem
  }
  
  if (board.temperature <= TEMP_MIN || board.temperature > TEMP_MAX) {
    status += "T"; // Temperature problem
  }
  
  return status.length() > 0 ? String(slaveId) + ":" + status : "";
}


bool hasAnySystemProblem() {
  for (int i = 1; i <= TOTAL_SLAVES; i++) {
    String status = getSlaveStatus(i);
    if (status.length() > 0) {
      return true; // Encontrou pelo menos um problema
    }
  }
  return false; // Sistema OK
}


void updateAlarmLed() {
  static bool alarmLedState = false;
  static unsigned long lastAlarmBlink = 0;
  
  if (hasAnySystemProblem()) {
    // Pisca LED vermelho a cada 1 segundo
    if (millis() - lastAlarmBlink >= 1000) {
      alarmLedState = !alarmLedState;
      digitalWrite(LED::red, alarmLedState ? HIGH : LOW);
      lastAlarmBlink = millis();
    }
  } else {
    // Sistema OK - LED vermelho apagado
    digitalWrite(LED::red, LOW);
    alarmLedState = false;
  }
}

void writeBufferToSD() {
  if (bufferCount == 0) {
    Serial.println("Buffer vazio, nada para gravar no SD.");
    return;
  }

  digitalWrite(TFT_CS, HIGH); // Garante que o display está desativado
  SPI.begin(SD_SCK, SD_MISO, SD_MOSI, SD_CS);
  digitalWrite(SD_CS, LOW);  // Ativa o pino de Chip Select do SD Card
  delay(10); // Pequena pausa para estabilizar

  if (!SD.begin(SD_CS)) {
    Serial.println("FALHA: Nao foi possivel inicializar o SD Card na operacao de escrita.");
    sdInitialized = false;
    // Limpa e sai, liberando o barramento
    digitalWrite(SD_CS, HIGH);
    SPI.end();
    return;
  }
  sdInitialized = true; // Se chegou aqui, a inicialização funcionou.
  
  File sdFile = SD.open(SD_FILE, FILE_APPEND);
  //File sdFile = SD.open("/testfile.txt", FILE_APPEND);
  if (!sdFile) {
    Serial.println("Failed to open file for writing");
    logErrorDisplay("Failed open SD file");
    //sdInitialized = false;
    digitalWrite(SD_CS, HIGH);
    SPI.end();
    return;
  }

  // Grava todos os dados do buffer
  for (int i = 0; i < bufferCount; i++) {
    String timestamp = getTimestamp();
    String date = timestamp.substring(0,10);
    String time = timestamp.substring(11);
    String dataLine = date + "," + time + "," + String(dataBuffer[i].id) + "," + 
                     String(dataBuffer[i].voltage, 4) + "," + 
                     String(dataBuffer[i].temperature, 2);
    
    sdFile.println(dataLine);
    Serial.println("Written: " + dataLine);
  }
  
  sdFile.close();
  Serial.printf("%d registros gravados com sucesso!\n", bufferCount);

  for(int i=0; i<10; i++){
    digitalWrite(LED::green, HIGH);
    delay(80);
    digitalWrite(LED::green, LOW);
    delay(80);
  }

  // Limpa o buffer após gravação bem-sucedida
  bufferCount = 0;
  
  // Libera o barramento SPI
  digitalWrite(SD_CS, HIGH);
  SPI.end();
  
  // Reativa o display se necessário
  setupDisplayForTFT();
}

void setupDisplayForTFT() {
  digitalWrite(SD_CS, HIGH);
  digitalWrite(TFT_CS, LOW);
  delay(50);
  SPI.begin(SD_SCK, SD_MISO, SD_MOSI, TFT_CS);
  tft.initR(INITR_BLACKTAB);
  tft.setRotation(1);
  digitalWrite(TFT_CS, HIGH);
  SPI.end();
}

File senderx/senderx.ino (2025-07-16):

#include <WiFi.h>
#include <esp_now.h>
#include <driver/rtc_io.h>
#include <OneWire.h>
#include <DallasTemperature.h>
#include <ADS1115_WE.h>
#include <Wire.h>
#include "LedAnimations.h"

#define uS_TO_S_FACTOR 1000000ULL
//#define TIME_TO_SLEEP  30*60
#define TIME_TO_SLEEP  300
#define ACK_TIMEOUT_MS 2000
//#define MAX_RETRIES 3     //@@implementation for resend payload after ACK NOK

#define BUTTON_PIN_BITMASK(GPIO) (1ULL << GPIO)  // 2 ^ GPIO_NUMBER in hex
#define USE_EXT0_WAKEUP          0               // 1 = EXT0 wakeup, 0 = EXT1 wakeup
#define WAKEUP_GPIO              GPIO_NUM_33     // Only RTC IO are allowed

#define I2C_ADDRESS 0x48  // ADS1115

#define NODE_ID 1

// Master's MAC
uint8_t masterMacAddress[] = {0x14, 0x33, 0x5C, 0x02, 0xED, 0x6C};

// Structure to send data. Must match the receiver structure
typedef struct struct_message {
  int id; // Unique for each sender
  float voltage;
  float temperature; 
} struct_message;

typedef struct {
  int id;
  bool ok;
} ack_message;

namespace US {
  const int trig = 26;
  const int echo = 27;
  const int limit = 20; // limit level in cm
}

namespace TMP {
  const int tmp_pin = 23;
  bool tmp_found = false;
}

RTC_DATA_ATTR int bootCount = 0;

volatile bool ackReceived = false;

// Create a struct_message called myData
struct_message myData;

// Create peer interface
esp_now_peer_info_t peerInfo;

// Create temp sensor object and temporary address
OneWire oneWire(TMP::tmp_pin);
DallasTemperature tmp_sensor(&oneWire);
DeviceAddress tmp_add;

// Create ADC object
ADS1115_WE adc(I2C_ADDRESS);


void setup() {
  Serial.begin(115200);
   
  pinMode(LED::yellow, OUTPUT);
  pinMode(LED::red, OUTPUT);
  pinMode(LED::green, OUTPUT);

  // Count boot resets
  ++bootCount;
  Serial.println("Boot number: " + String(bootCount));

  setupESPNow();
  configureWakeups();

  esp_sleep_wakeup_cause_t wakeup_reason= esp_sleep_get_wakeup_cause();

  if (wakeup_reason == ESP_SLEEP_WAKEUP_EXT0){
    checkLevelUntilLimit();
  } else if (wakeup_reason == ESP_SLEEP_WAKEUP_TIMER){
    initSensors();
    measureSensors();
    sendPayloadAndWaitAck();
  } else {
    Serial.println("First Boot");
  }
  ledTurnOff();
  
  esp_deep_sleep_start();
}


void loop() { } // EMPTY


void configureWakeups() {
  // Configure wakeup via button (EXT0)
  esp_sleep_enable_ext0_wakeup(WAKEUP_GPIO, 1);
  rtc_gpio_pullup_dis(WAKEUP_GPIO);
  rtc_gpio_pulldown_en(WAKEUP_GPIO);

  // Configure wakeup source every "TIME_TO_SLEEP" seconds
  esp_sleep_enable_timer_wakeup(TIME_TO_SLEEP * uS_TO_S_FACTOR);
  Serial.println("Setup ESP32 to sleep for every " + String(TIME_TO_SLEEP) + " Seconds");
  Serial.println("Going to sleep now");
  Serial.flush(); 
}


void setupESPNow(){
  // Set device as a Wi-Fi Station
  WiFi.mode(WIFI_STA);

  // Init ESP-NOW
  if (esp_now_init() != ESP_OK) {
    Serial.println("ERROR initializing ESP-NOW");
    return;
  }
  
  // Register for Send and Recv CB to get the status of packets
  esp_now_register_send_cb(onDataSent);
  esp_now_register_recv_cb(onAckRecv);
  Serial.println("Successfully initialized ESP-NOW");
  
  // Register peer
  memcpy(peerInfo.peer_addr, masterMacAddress, 6);
  peerInfo.channel = 0;  
  peerInfo.encrypt = false;
  
  // Add peer        
  if (esp_now_add_peer(&peerInfo) != ESP_OK){
    Serial.println("FAILED to add peer");
    return;
  }
}

// callback when data is sent
void onDataSent(const uint8_t *mac_addr, esp_now_send_status_t status) {
  Serial.print("\r\nLast Packet Send Status:\t");
  Serial.println(status == ESP_NOW_SEND_SUCCESS ? "Delivery Success" : "Delivery FAIL");
}


void onAckRecv(const esp_now_recv_info_t *mac, const uint8_t *data, int len) {
  ack_message *ack = (ack_message *)data;
  if (ack->id == NODE_ID && ack->ok) {
    ackReceived = true;
  }
}

void sendPayloadAndWaitAck() {
  ackReceived = false;
  esp_now_send(masterMacAddress, (uint8_t *)&myData, sizeof(myData));

  unsigned long start = millis();
  while (!ackReceived && millis() - start < ACK_TIMEOUT_MS) {
    // Wait callback to set ackReceived
    ledNewData();
    ledUpdateNewData();
    ledUpdateBlinking(); 
    delay(20);
  }
  
  if (ackReceived) {
    Serial.println("ACK OK recevied from master");
    ledAnimationBlinking(LED::green, 10);
  } else {
    Serial.println("ACK NOK (timeout)");
    ledAnimationBlinking(LED::red, 10);
  }
}


void initSensors(){
  // Init voltage adc - ADS1115
  Wire.begin();
  if(!adc.init()){
    Serial.println("ADS1115 not found!");
  }
  adc.setVoltageRange_mV(ADS1115_RANGE_6144);
  adc.setMeasureMode(ADS1115_CONTINUOUS);

  // Init temp sensor - DS18B20
  tmp_sensor.begin();
  if (tmp_sensor.getAddress(tmp_add, 0)){
    TMP::tmp_found = true;
  } else {
    Serial.println("DS18B20 not found at init!");
    TMP::tmp_found = false;
  }
}


void measureSensors(){
  float voltage = getVoltage();
  float temperature = getTemperature();

  myData.id = NODE_ID;
  myData.voltage = voltage;
  myData.temperature = temperature;
}


float getVoltage(){
  // Reading voltage - ADS1115
  float voltage = 0.0;
  const int samples = 5;
  float sum = 0.0;
  
  adc.setCompareChannels(ADS1115_COMP_0_GND);

  for (int i = 0; i < samples; i++){
    sum += adc.getResult_V();
    delay(50);
  }
  
  voltage = sum / samples;
  Serial.print("Pin A0: ");
  Serial.print(voltage, 2);
  
  return voltage; // alternative: getResult_mV for Millivolt
}


float getTemperature(){
  // Reading temp sensor - DS18B20
  if (!TMP::tmp_found){
    return -127.0;
  }
  
  const int samples = 5;
  int readings = 0;
  float sum = 0.0;

  for (int i = 0; i < samples; i++){
    tmp_sensor.requestTemperatures();
    float tempC = tmp_sensor.getTempC(tmp_add);
    if (tempC != -127.0 && tempC != 85.0){
        sum += tempC;
        readings++;
      }
    
    delay(300);
  }

  float average = readings > 0 ? sum / readings : -127.0;
  Serial.printf("Temp average: %.2f°C (%d valid readings)\n", average, readings);
  
  return roundf(average * 100.0) / 100.0;
}


void checkLevelUntilLimit() {
  const int samples = 5;
  float distance_cm = 0;
   pinMode(US::echo, INPUT);
  pinMode(US::trig, OUTPUT);

  do{

    float sum = 0;

    for (int i = 0; i < samples; i++){
      digitalWrite(US::trig, LOW);
      delayMicroseconds(2);
      digitalWrite(US::trig, HIGH);
      delayMicroseconds(10);
      digitalWrite(US::trig, LOW);

      long duration = pulseIn(US::echo, HIGH, 30000); // timeout 30 ms
      float us_read = duration * 0.0343 / 2;

      sum += us_read;
      delay(50);
    }

    distance_cm = sum / samples;
    
    Serial.printf("Level: %.1f cm\n", distance_cm);
    ledAnimationSnake();
    delay(100);
  } while (distance_cm > US::limit);
  
  ledAnimationBlinking(LED::green, 20);
}

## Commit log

2025-07-13 ack, button wakeup, US added
2025-07-14 Split sensor functions; LED functions; Average sensors measurements
2025-07-15 led animation added; average US; bug ackrev resolved
    [senderx.ino]
2025-07-16 master reworked; ACK; SD card logic; led libs
    [LedAnimations.cpp, master.ino, senderx.ino]
2025-07-17 display&joystick logic with menu; data struct splitted; get Mac ESP32 example; bug ESP32 stuck on led loops; setup functions
    [DataStructures.h, MenuManager.cpp, getMacSTA.ino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]
2025-07-18 sender->slave; resolved bug flicker display; animation display; getMAC improved; scanI2C example for RTC; KiCAD project created
    [wetlands_master_PCB.kicad_pcb, wetlands_master_PCB.kicad_sch]
2025-07-19 Moved test to specif folder; master setup reorganized; register slave; setupSD reworked + added handleJoystick func; errorMsgACK; scanI2C;
    [MenuManager.cpp, TestRTC.ino, TestSD.ino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]
2025-07-29 bug SPI modules conflict resolved
    [DataStructures.h, LedAnimations.cpp, MenuManager.cpp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]
2025-09-19 3D Files, PCB board, code update
    [Assem3.SLDASM, B_Side.SLDPRT, B_Side.STL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]
2025-09-24 Incresed container volume; Updated screen menu
    [B_Side.SLDPRT, B_Side.STL, Bottom.SLDPRT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]
2025-09-26 Menu reworked; ESP-NOW updated
    [DataStructures.h, MenuManager.cpp, master.ino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]
2025-09-26 Bug menu fixed; ACK message reworked
    [MenuManager.cpp, master.ino, slavex.ino]
2025-09-26 SPI bug fixed; ACK bug fixed
    [TestSPI.ino, master.ino]
2025-09-29 increased voltage range; better mV visualization; bug timeout fixed
    [DataStructures.h, MenuManager.cpp, TestSensors.ino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]
2025-09-30 Timestamp in .csv subdivided; min temp fixed
    [DataStructures.h, master.ino]
2025-10-27 Collect data timer increased
